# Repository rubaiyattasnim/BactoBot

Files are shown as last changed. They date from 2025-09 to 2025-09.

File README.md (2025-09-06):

# BactoBot: A Low-Cost, Bacteria-Inspired Soft Underwater Robot

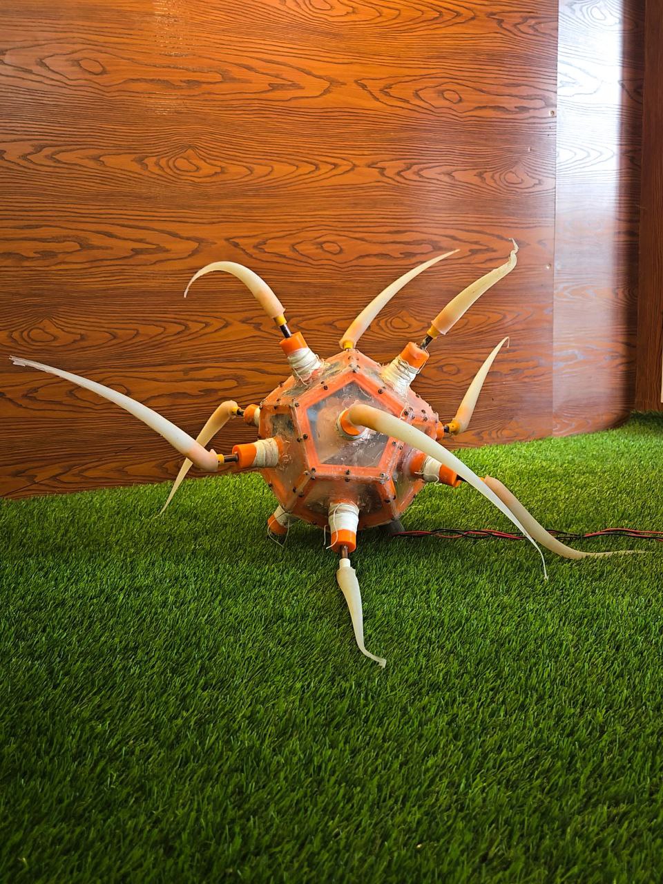
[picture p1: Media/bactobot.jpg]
BactoBot

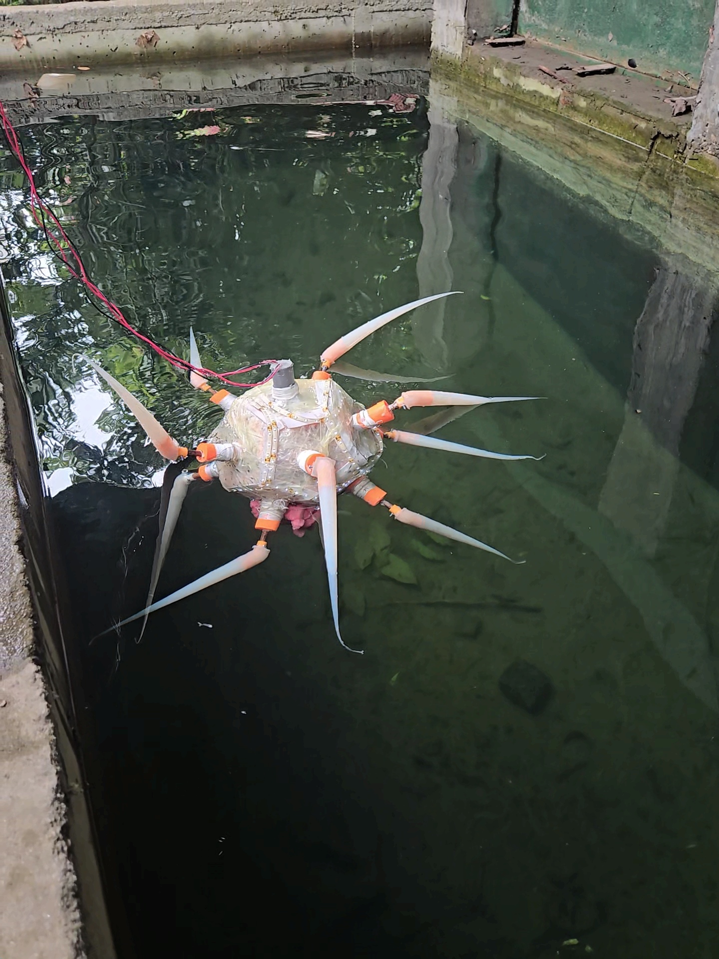
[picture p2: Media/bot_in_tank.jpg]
BactoBot operating in the test tank


BactoBot is a low-cost, soft underwater robot designed for safe and gentle marine exploration. It is inspired by the highly efficient flagellar propulsion of bacteria and built with accessible, DIY-friendly methods. This project was developed for the ME366: Electro-Mechanical System Design and Practice course at Bangladesh University of Engineering & Technology (BUET).

**[Watch the BactoBot in Action on YouTube](https://youtube.com/playlist?list=PLP1MpXDFlhkGGiaM0PEvsT2b7slWMGMUH&si=1uSfNwjm8kVEyjde)**

---

## Concept and Inspiration

Traditional rigid ROVs, with their high-speed propellers, pose a significant risk to delicate ecosystems like coral reefs. This project draws its primary inspiration from the **ZodiAq** robot, a groundbreaking design from Khalifa University, which demonstrated the potential of using multiple flexible, bacteria-like flagella for underwater locomotion.

BactoBot serves as an accessible, open-source implementation of this concept. By leveraging 3D printing, silicone molding, and common hobbyist electronics, it aims to provide a functional proof-of-concept for a safer, more compliant class of underwater drones.

*   **Primary Reference:** Mathew, A. T., et al. (2025). "ZodiAq: An Isotropic Flagella-Inspired Soft Underwater Drone for Safe Marine Exploration." *Soft Robotics*.
*   **DOI:** [10.1089/soro.2024.0036](https://doi.org/10.1089/soro.2024.0036)
*   **Preprint:** [arXiv:2403.19556](https://arxiv.org/abs/2403.19556)

## Table of Contents
- [Key Features](#key-features)
- [System Architecture](#system-architecture)
  - [Mechanical Design](#mechanical-design)
  - [Electrical System](#electrical-system)
- [Bill of Materials (BOM)](#bill-of-materials-bom)
- [Build Instructions](#build-instructions)
- [Future Work & Research Directions](#future-work--research-directions)
- [Contributors](#contributors)
- [Supervisors & Acknowledgements](#supervisors--acknowledgements)
- [License](#license)

## Key Features
- **Soft, Flexible Actuators:** 12 silicone-molded flagella that passively deform into a propulsive helical shape when rotated.
- **Redundant & Robust Design:** A 12-faced dodecahedron frame provides inherent redundancy; the robot can maintain mobility even with the failure of one or more arms.
- **Low-Cost & Replicable:** Built with readily available components and 3D-printed parts, making the design accessible to other researchers and hobbyists.
- **Inherently Safe:** The propeller-less design and soft arms minimize the risk of damaging fragile marine life during exploration.

## System Architecture

### Mechanical Design
The core structure is a **dodecahedron frame** assembled from 12 3D-printed PETG faces, providing symmetric mounting points for the actuators. The 12 propulsive **flagella** were molded from food-grade silicone rubber for high flexibility and safety. Each flagellum is coupled to a motor shaft via a rigid, 3D-printed hook embedded during casting.

- **CAD Files:** All design files, in both native SolidWorks (`.SLDPRT`) and universal STEP (`.step`) formats, are available in the `/CAD` directory.

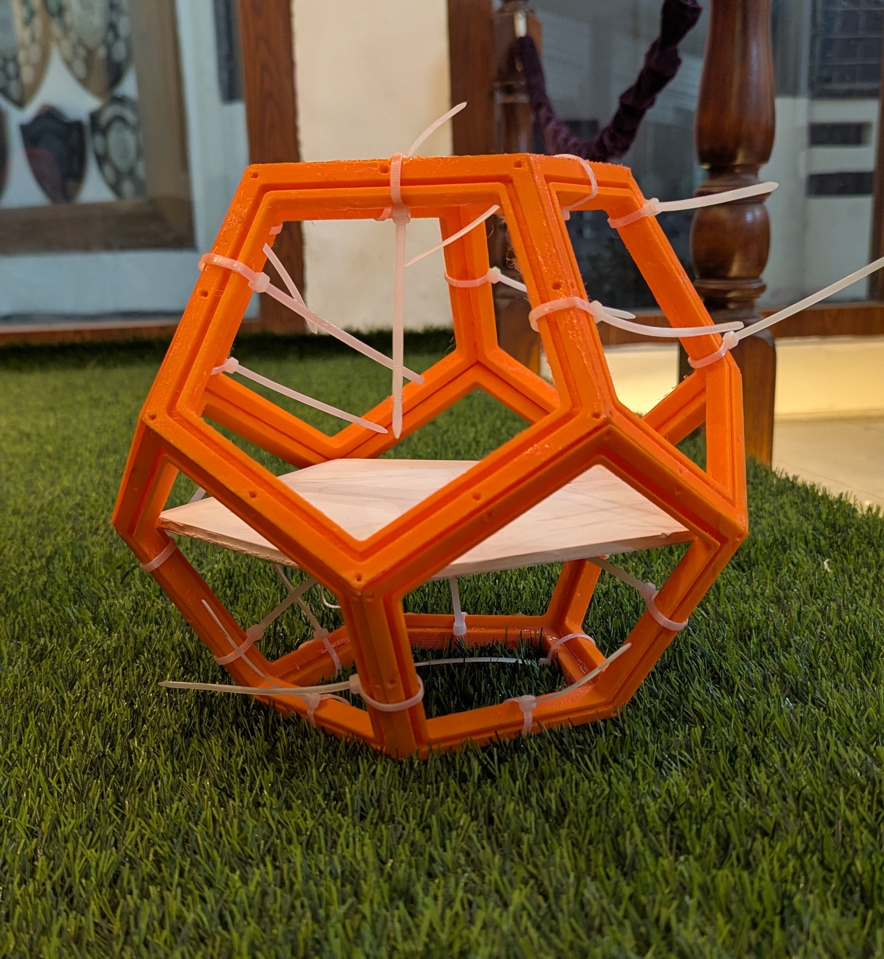
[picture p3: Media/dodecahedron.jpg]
The 3D-printed PETG dodecahedron frame during assembly.

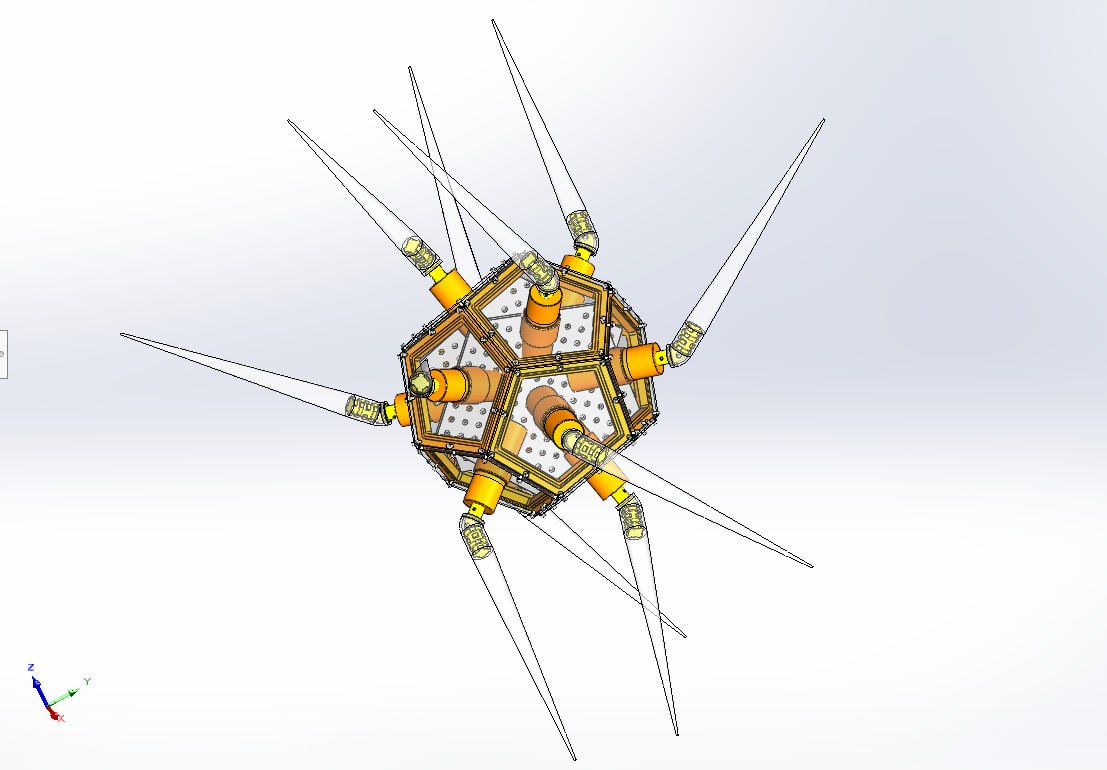
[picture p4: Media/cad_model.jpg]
Final CAD assembly showing the arrangement of the 12 flagella.


### Electrical System
The system is controlled by an **Arduino Mega 2560**. To accommodate significant space constraints within the dodecahedron frame, the 12 motors are driven in opposing pairs. Each pair is wired in parallel and controlled by a single **BTS7960 High-Current H-Bridge**, for a total of 6 driver modules.

This parallel configuration is highly effective for the primary maneuvers of forward motion, reverse, and turning. The primary trade-off for this space-saving design is the loss of individual control over each of the 12 flagella.

A buck converter steps down the main battery voltage to provide stable 5V power to the Arduino via its `VIN` pin.

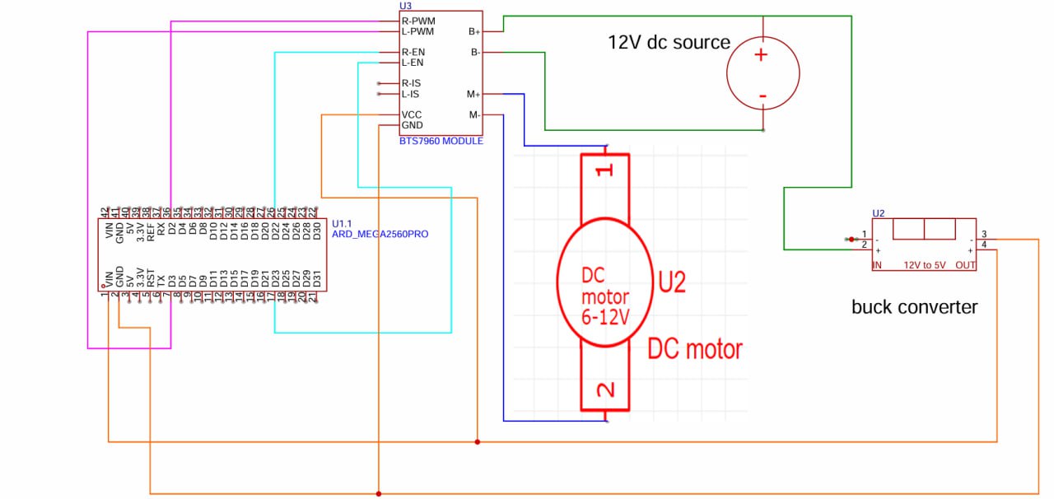
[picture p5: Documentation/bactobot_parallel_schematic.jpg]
Schematic showing two motors wired in parallel to a single driver unit. This circuit is replicated 6 times.


## Bill of Materials (BOM)
The total estimated cost at the time of construction was approximately **43,359 BDT (~$370 USD)**.

<details>
<summary><b>Click to expand the full Bill of Materials</b></summary>

### Electrical Components
| Component | Quantity | Notes |
| --- | --- | --- |
| Arduino Mega 2560 R3 | 1 | Central microcontroller. |
| BTS7960 Motor Driver Module| 6 | High-current H-bridge. See Electrical System section for wiring. |
| DC Geared Motor | 12 | 12V, 100RPM, 25GA High Torque. |
| 3S LiPo Battery | 1 | 3300mAh with XT60 connector recommended. |
| Jumper Wires & Hookup Wire | 1 Set | Assorted lengths and gauges for signal and power. |

### Structural & Mechanical Components
| Component | Quantity | Notes |
| --- | --- | --- |
| Silicone Rubber | ~1.75 kg | For molding the 12 flexible flagella. |
| 3D Printed Parts | 1 Set | PETG filament. Includes frame, motor canisters, hooks, and molds. |
| Laser Cut Faceplates | 12 | Acrylic or similar waterproof material. |
| Motor Shafts | 12 | Mild Steel. |
| Fasteners | 1 Set | Assorted M3 screws, cord screws, nuts, and bolts. |
| Adhesives | 1 Set | Epoxy and B7000 for permanent assembly. |

### Waterproofing & Buoyancy Components
| Component | Quantity | Notes |
| --- | --- | --- |
| O-Rings | ~31 | 16 Small, 15 Large for sealing motor shafts and faceplates. |
| Sealants & Lubricants | 1 Set | Silicone sealant, grease, and light machine oil. |
| Tapes & Consumables | 1 Set | Thread seal tape, electrical tape, foam, etc. |
| Ballast Weights | ~5 kg | Lead or steel weights for achieving neutral buoyancy. |

</details>

## Build Instructions
This guide outlines the fabrication and assembly of the BactoBot prototype.

### 1. Component Fabrication
-   **3D Printing:** Using the files in `/CAD`, print all structural components (frames, motor cannister assmeblies, flagellar hooks). **PETG** is recommended.
-   **Silicone Molding:** Cast **12 flexible flagella** using the 3D-printed molds. Remember to embed a rigid `Hook` at the base of each arm before the silicone cures.
-   **Laser Cutting:** Cut **12 hexagonal faceplates** from 3mm acrylic sheet. Include 2 racks to hold the electronics inside the structure.

### 2. Mechanical & Electrical Assembly
-   **Frame Construction:** Assemble the 12 printed faces into a **dodecahedron** using strong epoxy.
-   **Motor Installation:** Mount the 12 DC motors inside their dedicated canisters.
-   **Wiring:** Install the Arduino, motor drivers, and all wiring according to the provided **schematic**. Ensure all connections are secure before sealing.

### 3. Waterproofing
This step is critical and requires meticulous attention to detail.
-   Follow the **multi-layer sealing protocol** detailed in the `/Documentation` folder.
-   Key steps include creating the dynamic **O-ring and grease seals** for the 12 rotating shafts and sealing all faceplates with silicone.
-   **Perform incremental leak tests** in shallow water before fully submerging the robot.

### 4. Software and Calibration
-   **Firmware Upload:** Upload the Arduino sketch from `/Code` to the microcontroller.
-   **Buoyancy Calibration:** In a test tank, add internal ballast weights incrementally until the robot achieves stable **neutral buoyancy**.

## Future Work & Research Directions
The current prototype successfully validates the core mechanical design and propulsion concept using a simple, open-loop control script. This provides a solid foundation for significant advancements, primarily in software, control systems, and autonomy. The following is a proposed roadmap for transforming BactoBot from a proof-of-concept into a capable research platform.

### 1. Advanced Software Architecture & Control
-   **Develop a Modular Control Library:** Refactor the current hardcoded Arduino script into a clean, function-based library. Create functions like `moveForward(speed)`, `turn(direction, speed)`, and `setFlagellaState(motor_index, state)`, which will make the code more readable, scalable, and easier to build upon.
-   **Implement a State Machine:** Transition from a simple time-based loop to a robust state machine (e.g., `IDLE`, `MOVING_FORWARD`, `TURNING`, `STATION_KEEPING`). This is essential for managing complex tasks and behaviors.

### 2. Real-Time Teleoperation
-   **Integrate Wireless Communication:** Add a wireless communication module (like Bluetooth or Wi-Fi) to enable real-time remote control.
-   **Develop a Ground Control Station:** Create a simple computer- or phone-based interface to send commands to the robot, view status data, and manually control its movement.

### 3. Closed-Loop Control & Stabilization
-   **Integrate an Inertial Measurement Unit (IMU):** This is the most critical hardware upgrade. An IMU (like the MPU-6050) provides real-time orientation feedback (roll, pitch, yaw).
-   **Develop a PID Control System:** Use the IMU data to implement a PID (Proportional-Integral-Derivative) controller to maintain a heading, perform precise turns, and achieve station-keeping.

### 4. Environmental Perception & Autonomy
-   **Add a Sensor Suite:** Enhance the robot with exteroceptive sensors like waterproof cameras for visual feedback, sonar for obstacle detection, and a depth sensor to maintain specific depths.
-   **Develop Autonomous Navigation Algorithms:** With a full sensor suite, research can then focus on implementing foundational robotics algorithms like obstacle avoidance and waypoint navigation.

## Contributors
*   **Ronojoy Roy** (Student ID - 2110142)
*   **Nayan Bala**  (Student ID - 2110158)
*   **Rubaiyat Tasnim Chowdhury**  (Student ID - 2110163)
*   **Tarek Mahmud**  (Student ID - 2110177)

## Supervisors & Acknowledgements
We express our sincere gratitude to our project supervisors for their invaluable guidance:
*   Dr. Kazi Arafat Rahman, Associate Professor, ME, BUET
*   Priom Das, Assistant Professor, ME, BUET
*   Sadia Tasnim, Lecturer, ME, BUET
*   Md. Moyeenul Hossain Ratul, Lecturer, ME, BUET

## License
This project is licensed under the MIT License. See the [LICENSE](LICENSE) file for details.

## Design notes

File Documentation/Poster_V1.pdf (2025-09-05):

# BactoBot - A Bacteria Inspired

# Underwater Soft Robot

## Abstract

## KEY COMPONENTS & MATERIALS

## FUTURE PROSPECTS

## PROJECT SUPERVISORS

## PREPARED BY

## For the course of ME 366: Electro-Mechanical System Design & Practice

## CHALLENGES & LIMITATIONS

## OPERATIONAL FLOW

## HOW IT WORKS: A FLAGELLAR PROPULSION SYSTEM

## KEY FEATURES

BactoBot is a soft underwater robot designed for safe marine exploration. Inspired by the whip-like tails (flagella) of bacteria, BactoBot has 12 flexible arms arranged in a dodecahedron shape. This

design makes it gentle for interacting with marine life and allows it to keep working even if some arms break. Utilizing readily available components, 3D printing, and accessible microcontrollers, we developed a bot capable of basic underwater navigation in controlled environments like tanks or pools.

Microcontroller: Arduino

Mega 2560 | Motor Driver: BTS 7960 43A | Motors: 12x High Torque DC
| | Geared Motors

Battery: 3300mAh 11.1V 3S
Lipo Battery

Power Management: On/Off
Slide Switch

Body Structure: 3D Printed Frame (PETG)

Front Faceplate: Acrylic

Sheet

Flexible Flagella: Molded Soft Silicone Rubber (Food Grade)

Others: Breadboard, Wiring, Waterproofing Sealants,

ballast

Showcasing the full potential of omnidirectional movement capabilities Implementing closed-loop control with an IMU for precise navigation Integrating sensors like cameras for enhanced perception
Improving battery life and power efficiency
Enhancing structural integrity and waterproofing for deeper operation Developing autonomous navigation capabilities.

Dr. Kazi Arafat Rahman, Associate Professor, ME, BUET Priom Das, Assistant Professor, ME, BUET
Md. Moyeenul Hossain Ratul, Lecturer, ME, BUET Sadia Tasnim, Lecturer, ME, BUET

Waterproofing: Achieving a reliable and watertight seal for all 12 rotating shafts and the main structural body was extremely challenging, especially while working within a limited budget. This was our primary and most persistent engineering challenge throughout development.

Control System: Our current control system is open-loop, meaning we can issue commands to the

motors, but the robot receives no feedback on its actual position or orientation. This lack of sensory input causes the system to gradually drift, reducing overall precision.

Buoyancy & Ballast: Precisely adjusting the robot to achieve neutral buoyancy is a slow and iterative process, involving repeated trial and error with different ballast weight configurations. Even

small changes in hardware or conditions can require re-balancing.

| Bacteria-Inspired Propulsion: Utilizes rotating flexible flagella, mimicking bacterial movement for efficient underwater thrust

| Soft Robotics Approach: Incorporates soft, compliant flagella for potentially safer interaction with the environment

| Redundancy: If one arm fails, others compensate, making the robot reliable in rough underwater environments

| Omnidirectional Movement: Designed for translation in multiple directions and rotation around its axis

| Low-Cost & DIY: Built using accessible components and 3D printing, making it cost-effective.

Simple Rotation, Complex Motion: A motor that generates a simple rotating force is located at the base of each soft arm. At first, the arm itself has a straight form rather than a propeller-like one.

Passive Deformation of Soft Arm: The flexible arm passively bends and twists into a stable helical shape as the motor spins it in the water. This is due to the hydrodynamic force of the water and the torque of the motor.

Thrust Generation: | The drone is propelled by | the thrust produced by this rotating
helix-shaped arm | pushing against the water.
CONCEPTUAL DESIGN | CAD MODELING | 3D PRINTING PARTS
ELECTRONIC ASSEMBLY | FRAME ASSEMBLY | WATERPROOFING & TESTING
PROGRAMMING & CALIBRATION | UNDERWATER TRIALS

Ronojoy Roy
2110142

Nayan Bala
2110158

Rubaiyat Tasnim
Chowdhury
2110163

Tarek Mahmud
2110177

# Bangladesh University of Engineering & Technology

Prepared by the students of

Scan QR Code to
Learn more

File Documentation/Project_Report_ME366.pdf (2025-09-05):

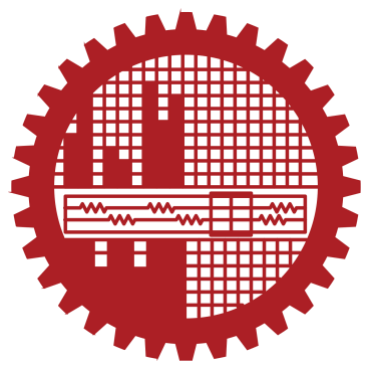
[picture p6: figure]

### Bangladesh University of Engineering & Technology (BUET)

Department of Mechanical Engineering

ME366: Electro-Mechanical System Design and Practice

Project Report: BactoBot

A Low-Cost, Bacteria-Inspired Soft Underwater Robot for Marine Exploration

Prepared By: Group C-11

- Ronojoy Roy (2110142)
- Nayan Bala (2110158)
- Rubaiyat Tasnim Chowdhury (2110163)
- Tarek Mahmud (2110177)

Project Supervisors:

- Dr. Kazi Arafat Rahman, Associate Professor, ME, BUET
- Priom Das, Assistant Professor, ME, BUET
- Sadia Tasnim, Lecturer, ME, BUET
- Md. Moyeenul Hossain Ratul, Lecturer, ME, BUET

Date: 31/07/2025

Abstract

Traditional rigid underwater vehicles pose risks to delicate marine ecosystems, such as coral reefs, due to their inflexible structures and high-speed propellers. This project, "BactoBot," addresses this challenge by developing a soft underwater robot designed for safe and gentle marine exploration. Inspired by the highly efficient flagellar propulsion of bacteria, BactoBot features 12 flexible, silicone-based arms arranged on a dodecahedral frame. This design provides inherent compliance, redundancy against single-point failures, and the potential for omnidirectional movement. Utilizing readily available components, 3D printing, and accessible microcontrollers, we successfully designed, fabricated, and tested a low-cost prototype capable of basic underwater navigation, including forward motion and turning, in a controlled environment. The project demonstrates the feasibility of replicating complex biological locomotion principles using DIY methods, paving the way for more affordable and environmentally-conscious robotic tools for marine science.

Table of Contents

### 1. Introduction

### 1.1 The Challenge of Underwater Exploration

The world's oceans are vast ecosystems teeming with life, much of which remains unexplored. Exploring delicate environments like coral reefs, underwater caves, and cluttered seabeds presents a significant challenge for robotics. Conventional Remotely Operated Vehicles (ROVs) are often rigid and powered by fast-spinning propellers, which can inadvertently damage fragile marine life and their habitats. The need for a safer, more adaptable, and accessible robotic platform is paramount for non-invasive marine research. The paradigm of soft robotics offers a compelling solution, enabling robots to interact with their environment in a safer, simpler, and more cost-effective manner.

### 1.2 Project Inspiration: Bacterial Flagella

This project draws its primary inspiration from one of nature's most efficient and unlikely swimmers: bacteria. The bacterial flagellum is the only known example of a true biological "wheel," a simple rotational motor that propels the organism. This project aims to replicate this unique locomotion strategy at a macro scale.

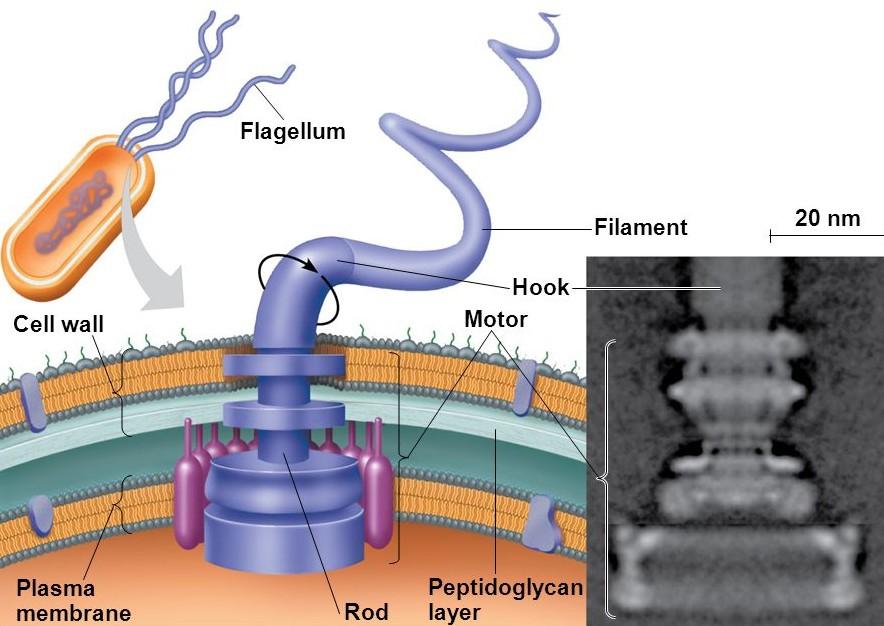
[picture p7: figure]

Figure 1: Structure of a Prokaryotic Flagellum, with motor, rigid hook and flexible filament.

### 1.3 Project Objectives

The primary goal of the BactoBot project was to design and build a budget-friendly, soft underwater robot based on the flagellar propulsion concept. Key objectives included:

- To design a redundant and robust mechanical structure using accessible materials.
- To replicate the passive deformation principle of flagellar propulsion.
- To implement a control system for basic underwater maneuvers (forward motion and turning).
- To overcome the practical engineering challenges of waterproofing and buoyancy on a limited budget.

### 2. Design and Fabrication

### 2.1 Mechanical Design

The mechanical structure of BactoBot was designed for robustness, redundancy, and ease of fabrication.

Body Frame: The core structure is a dodecahedron (a 12-faced shape) fabricated from 3D-printed PETG. This geometry was chosen because it allows for the symmetric placement of 12 arms, providing inherent design redundancy and the potential for omnidirectional movement.

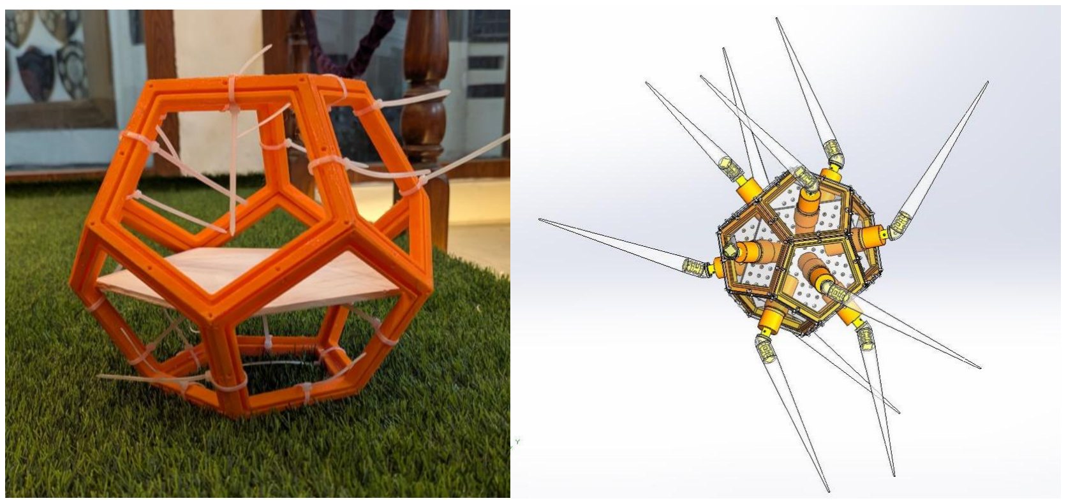
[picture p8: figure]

Figure 2: (Left) The 3D-printed dodecahedron frame. (Right) CAD model showing the full assembly.

Flagella: The 12 propulsive arms were molded from food-grade silicone rubber. This material makes the flagella highly flexible and safe for potential environmental interaction.

Each flagellum is designed as a straight, tapered arm that deforms passively into a propulsive shape in water.

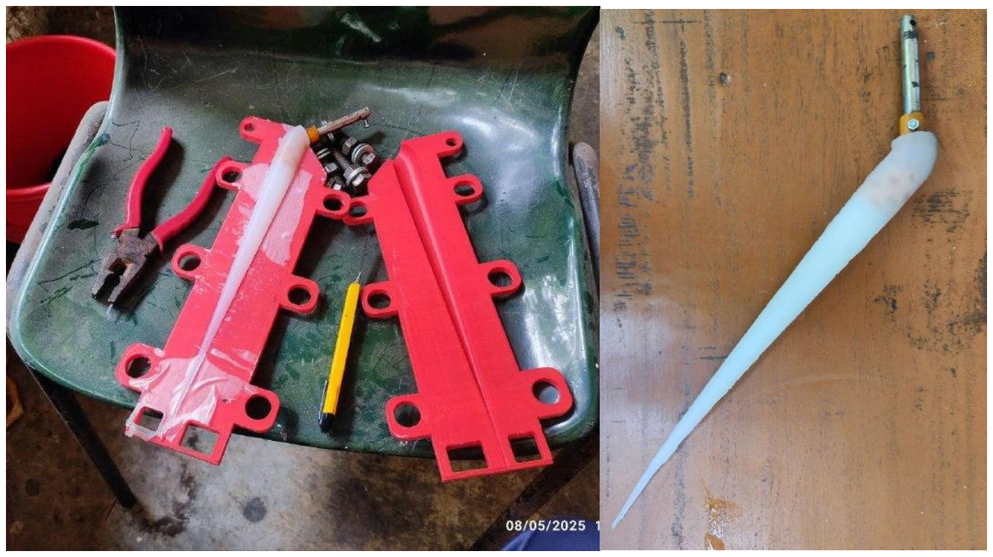
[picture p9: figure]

Figure 3: (Left) Flagellum inside its mold. (Right) Flagellum with hook and motor shaft attached.

Waterproofing: Sealing the main body and 12 rotating motor shafts was a primary challenge. A multi-layered approach was used:

- Acrylic faceplates for each of the 12 faces.
- Specially designed, 3D-printed canisters to house the motors.
- O-rings to create a primary seal.
- Waterproof sealants (silicone, thread tape, grease) applied to all joints and potential points of ingress.

### 2.2 Electrical System and Actuation

The electrical system was designed with widely available and robust components suitable for a DIY project.

- The Brain: An Arduino Mega 2560 serves as the central microcontroller, chosen for its large number of I/O pins and strong community support.
- Actuation: Propulsion is driven by 12 high-torque DC geared motors, one for each flagellum.

- Motor Control: Each motor is controlled by a dedicated BTS7960 high-current motor driver, allowing for precise control of speed and direction.
- Power: The entire system is powered by a high-discharge 11.1V (3S) LiPo battery.

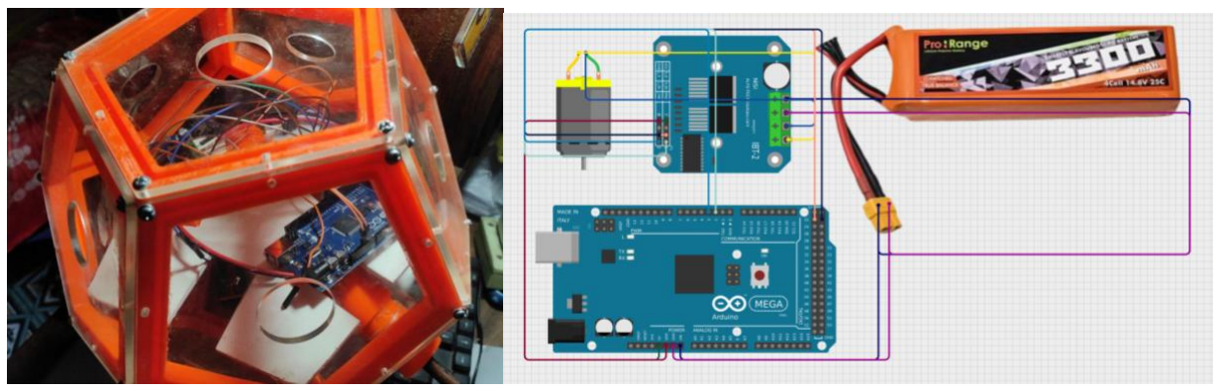
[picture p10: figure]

Figure 4: (Left) The assembled electronics inside the frame. (Right) The basic circuit diagram for a single motor.

### 3. Flagellar Locomotion Principle

### 3.1 Passive Deformation for Propulsion

Unlike a conventional propeller, BactoBot's locomotion is not based on a pre-formed rigid blade. Instead, it relies on the principle of passive deformation, a core concept in soft robotics.

1. A simple rotational torque is applied at the base of each straight, flexible arm by the DC motor.
2. As the arm rotates in the water, hydrodynamic forces cause it to bend and twist.
3. The arm passively deforms into a stable, helical (corkscrew) shape.
4. This rotating helical shape acts as a propeller, generating thrust by pushing against the water.

This method allows for complex propulsive motion to be generated from a very simple input (rotation), with the physics of the soft material and fluid interaction handling the complexity.

### 3.2 Control Strategy for Movement

By coordinating the rotation of the 12 arms, different maneuvers can be achieved. Our current implementation is open-loop.

- Forward Motion: To move in a straight line, opposing pairs of motors are activated. By rotating in directions that cancel out their rotational torques on the main body, a net thrust is generated, pushing the robot forward.

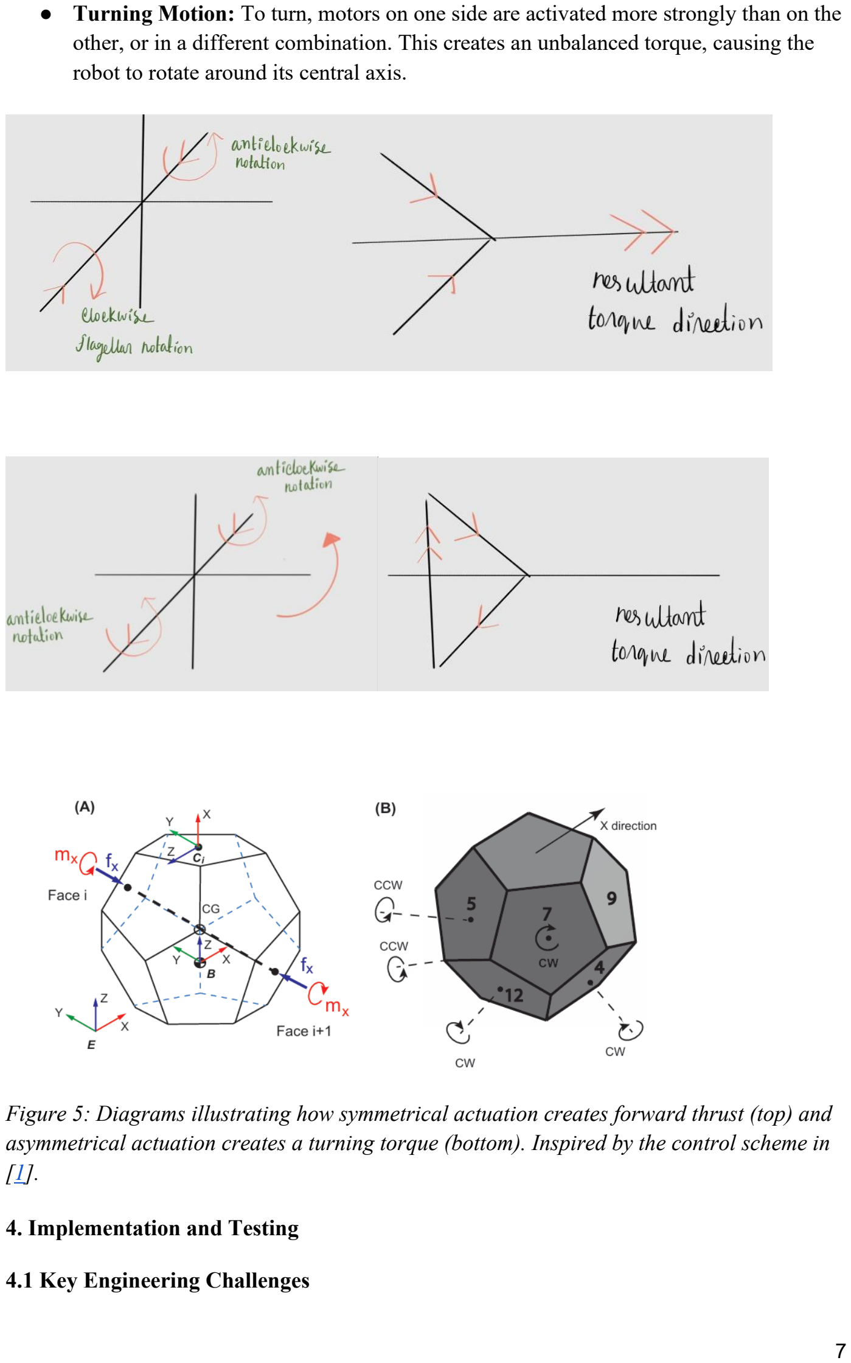
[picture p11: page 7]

- Turning Motion: To turn, motors on one side are activated more strongly than on the other, or in a different combination. This creates an unbalanced torque, causing the robot to rotate around its central axis.

Figure 5: Diagrams illustrating how symmetrical actuation creates forward thrust (top) and asymmetrical actuation creates a turning torque (bottom). Inspired by the control scheme in [1].

### 4. Implementation and Testing

### 4.1 Key Engineering Challenges

- Waterproofing: Achieving a reliable, dynamic seal for 12 rotating shafts on a budget was our primary engineering challenge. Our strategy involved multiple layers of protection, from O-rings to liberal use of silicone sealant and poly-wrapping the entire robot during initial tests. This iterative process of sealing, testing, and re-sealing was critical to the project's success.
- Buoyancy and Ballast: Precisely balancing the robot to be neutrally buoyant was a tedious process of trial and error. Small ballast weights had to be carefully added and positioned inside the frame to counteract the weight of the components and achieve a stable orientation in the water.

### 4.2 Testing Environment and Results

BactoBot was successfully tested in a controlled tank environment. The tests validated the core design and functionality of the prototype.
The key results were:
1. No Water Leaks: The multi-layered waterproofing strategy proved effective during the testing period.
2. Achieved Locomotion: The robot successfully demonstrated both forward motion and turning maneuvers based on the open-loop commands sent to the motors.
3. Stable Operation: The robot maintained a stable orientation and depth during basic maneuvers, confirming the success of the buoyancy and ballast balancing.

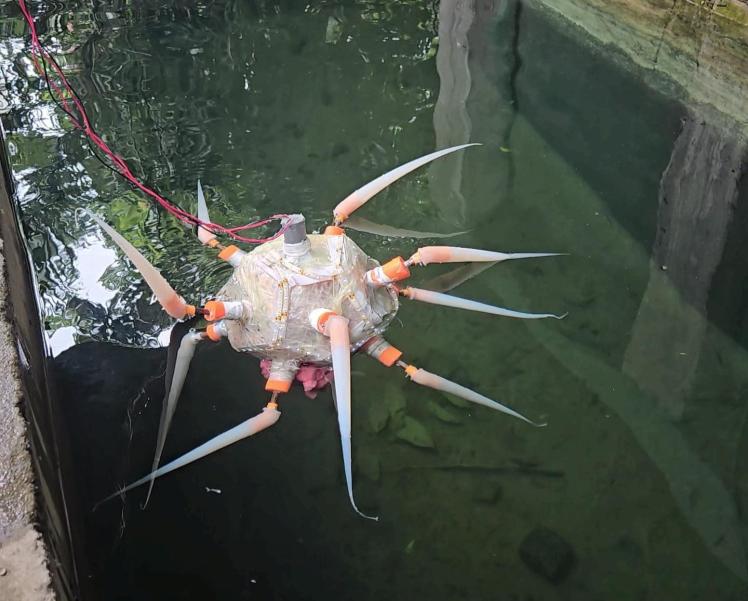
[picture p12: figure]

Figure 6: BactoBot submerged and operating in the test tank.

Watch here:
https://youtube.com/playlist?list=PLP1MpXDFlhkGGiaM0PEvsT2b7slWMGMUH&si=1uSfNwjm8k VEyjde (https://youtube.com/playlist?list=PLP1MpXDFlhkGGiaM0PEvsT2b7slWMGMUH&si=1uSfNwjm8kVEyjde)

### 5. Conclusion and Future Work

### 5.1 Conclusion

This project successfully met its objectives to design, build, and test a low-cost, bacteria-inspired soft underwater robot. We proved that the advanced concept of flagellar propulsion can be replicated using accessible DIY methods and materials. BactoBot stands as a functional proof-of-concept, demonstrating a promising path towards creating safer, more affordable, and more accessible robots for the critical task of marine exploration.

### 5.2 Recommendations for Future Work

BactoBot provides a solid foundation for further development. Future work should focus on:

- Implementing Closed-Loop Control: Integrating an Inertial Measurement Unit (IMU) to provide feedback on the robot's orientation. This would allow for a closed-loop control system for precise navigation and station-keeping.
- Enhanced Perception: Integrating sensors like waterproof cameras to provide a visual feed, transforming the robot from a purely locomotive platform to a true exploration tool.
- Improved Waterproofing and Durability: Refining the mechanical design for more robust and long-term waterproofing to allow for deeper and more extended operation.
- Autonomous Navigation: Developing algorithms for autonomous navigation to allow the robot to perform exploration tasks with minimal human intervention.

### 6. Acknowledgements

We would like to express our sincere gratitude to our project supervisors—Dr. Kazi Arafat Rahman, Priom Das, Sadia Tasnim, and Md. Moyeenul Hossain Ratul—for their invaluable guidance, support, and encouragement throughout this project.

### 7. References

[1] Mathew, A. T., Feliu-Talegon, D., Abdullahi Adamu, Y., et al. (2025). "ZodiAq: An Isotropic Flagella-Inspired Soft Underwater Drone for Safe Marine Exploration." Soft Robotics. Published at: https://doi.org/10.1089/soro.2024.0036. (Preprint available at: https://arxiv.org/abs/2403.19556)

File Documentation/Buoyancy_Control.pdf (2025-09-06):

# Achieving Neutral Buoyancy in Underwater Robotics

In our aquatic robotics project, we meticulously controlled buoyancy using the neutral buoyancy method. This involves precisely adjusting the robot's mass until its overall density matches that of water. Our process involved a combination of theoretical calculations and practical experimentation.
We leveraged SolidWorks for accurate volume determination and cross-referenced this with ChatGPT for predictive mass estimations required to achieve neutral buoyancy. This dual approach provided a strong foundation for our weight distribution strategy.
The iterative trial-and-error process was crucial. We incrementally added weights, starting with six 500g weights and then two 1kg weights, refining the robot's submergence. The final adjusted total weight for neutral buoyancy was approximately 11.25 kg.

Volume Calculation
Initial volume determined via SolidWorks
and validated through AI-assisted
computations for mass prediction.

Iterative Weighting
Deployment of 500g and 1kg weights in a trial-and-error approach to fine-tune buoyancy.

Target Buoyancy Achieved
Successful neutral buoyancy attained at a cumulative mass of 11.25 kg, ensuring stable underwater operation.

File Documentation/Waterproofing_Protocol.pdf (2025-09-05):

# Advanced Waterproofing Techniques for Electrical and Mechanical Assemblies

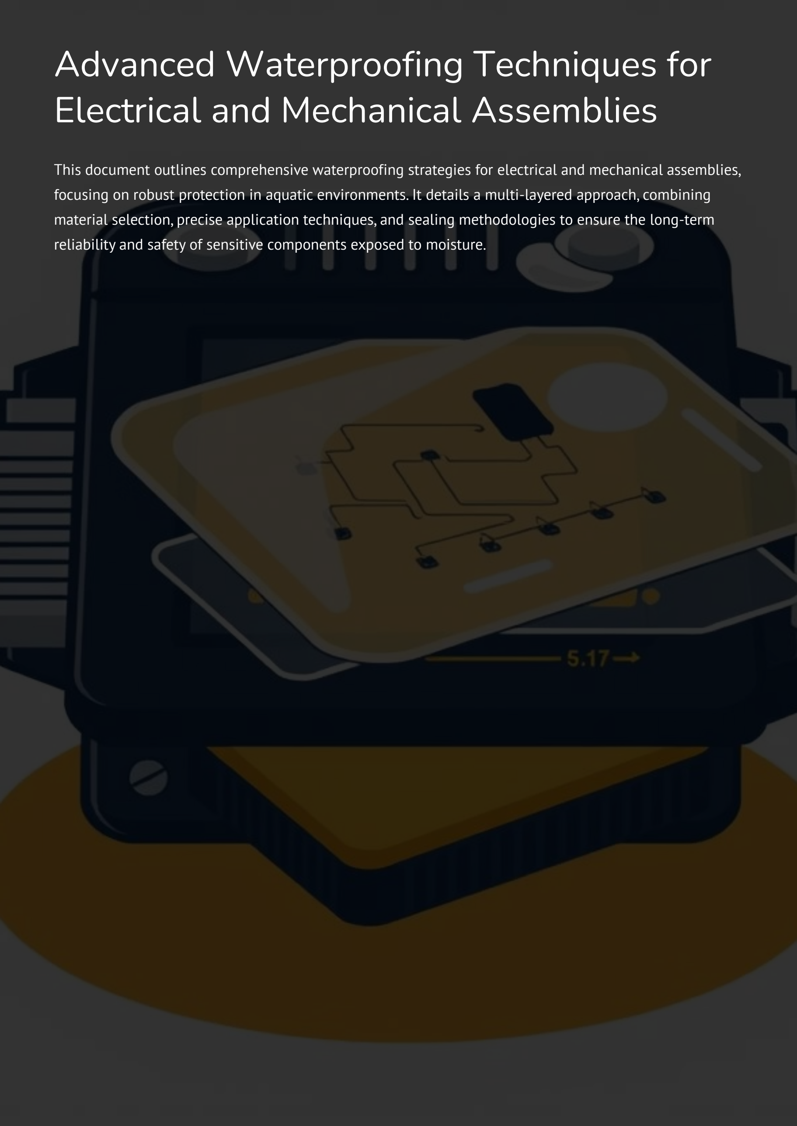
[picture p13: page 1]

This document outlines comprehensive waterproofing strategies for electrical and mechanical assemblies, focusing on robust protection in aquatic environments. It details a multi-layered approach, combining material selection, precise application techniques, and sealing methodologies to ensure the long-term reliability and safety of sensitive components exposed to moisture.

# Multi-Layered Waterproofing Protocol for Aquatic Systems

Effective waterproofing in aquatic projects demands a meticulous, multi-tiered approach to safeguard sensitive electrical and mechanical components from water ingress and potential damage. Our protocol integrates primary, secondary, and tertiary barriers, ensuring redundancy and enhanced protection.

## Primary Encapsulation (Poly Wrap)

Each individual electrical component is initially wrapped using a high-density poly roll. This serves as the first line of defence, providing temporary protection against incidental water exposure during assembly or in the event of a breach in outer layers. This initial wrapping also aids in shock absorption and vibration damping.

## Terminal Sealing (Araldite & Hot Glue)

Critical entry points, such as the motor's two-wire connection points, are meticulously sealed. Araldite epoxy glue is applied to form a durable, watertight bond around these connections. Once dry, an additional layer of hot glue is applied over the cured epoxy, providing extra mechanical strength, vibration resistance, and a secondary hermetic seal. This two-stage application method significantly enhances the long-term integrity of the seal.

## Structural Edge and Joint Sealing

Following the assembly of the dodecahedron structure, all external edges are sealed with a high-performance, marine-grade sealant. Particular attention is paid to the connecting area between the main structural plates and the motor canister. Due to the confined space, Araldite epoxy is precisely applied here to create an impermeable barrier. This step prevents capillary action and direct water penetration into the assembly's interior.

Recognising the potential for residual moisture or condensation within the motor canister, an internal defence mechanism is employed. Foam, pre-saturated with Mobil oil, is strategically placed around the motor. This oil-impregnated foam serves a dual purpose: it acts as a hydrophobic barrier, repelling any water droplets, and provides continuous lubrication to the motor components, preventing corrosion and ensuring smooth operation even in humid conditions. A layer of grease is then applied over this foam for additional protection.

## Internal Motor Protection & Lubrication

The crucial joint between the motor shaft and the main shaft, housed within a small canister, is filled with high-viscosity grease. A customised O-ring is fitted on the upper part of this small canister. Furthermore, a second customised O-ring is positioned just below and inside the upper face of the main motor canister. The space between these two O-rings is generously filled with grease, creating a dynamic hydrostatic seal. A final, smaller O-ring is placed just above the upper motor canister's upper face, serving as an additional splash guard and environmental seal. This multi-O-ring and grease-filled chamber system provides unparalleled protection against water ingress along the rotating shaft.

## Advanced Shaft and O-Ring Seal System

After all internal sealing and assembly, the entire structure is wrapped multiple times with poly roll for comprehensive external protection. This layer acts as a sacrificial barrier against abrasion and minor impacts. Finally, high-strength scotch tape is applied to stabilise the poly wrap, ensuring it remains securely in place and maintains its integrity under operational conditions.

## External Reinforcement (Poly Wrap & Tape)

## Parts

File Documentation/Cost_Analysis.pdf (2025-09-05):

TABLE 1: COST ANALYSIS OF STRUCTURAL COMPONENTS

Component | Unit Cost(BDT) | Quantity | Subtotal(BDT)
Silicone | 2980/kg | 1.75kg | 5215
3D Print (Mold) | 2500 | 1 | 2500
3D Print (Frame, Canister, Hook) | 940 | 12 | 11280
Laser Cutting (Faceplate) | 175 | 12 | 2100
Shaft (Mild Steel) | 35 | 12 | 420
Screw (3-mm) | 1.75 | 150 | 260
Cord Screw | 5 | 15 | 75
Nut Bolts (Big) | 25 | 6 | 150
Nut Bolts (Small) | 6 | 15 | 90
Glue (B7000) | 150 | 2 | 300
Glue (Epoxy) | 120 | 5 | 600
Hard Board (Rack) | --- | --- | 150
Total Cost | | | 23140

TABLE 2: COST ANALYSIS OF ELECTRICAL COMPONENTS

Component | Unit Cost(BDT) | Quantity | Subtotal(BDT)
Arduino Mega 2560 R3 | 1788 | 1 | 1788
Motor Driver 43A BTS7960
| 420 | 6 | 2520
High Torque DC Gear Motor
12V 100RPM 25GA | 750 | 12 | 9000
Jumper Wires | 95 | 3 | 285
Battery | 75 | 1 | 75
Lipo Battery 3300mAh 7.4V 2S | 2750 | 1 | 2750
Wire | --- | --- | 150
Total Cost | | | 16568

TABLE 3: COST ANALYSIS OF BUOYANCY CONTROL COMPONENTS

Component | Unit Cost(BDT) | Quantity | Subtotal(BDT)
Weights (1kg) | 80 | 2 | 160
Weights (500g) | 40 | 6 | 240
Total Cost | | | 400

TABLE 4: COST ANALYSIS OF WATERPROOFING COMPONENTS

Component | Unit Cost(BDT) | Quantity | Subtotal(BDT)
Polythene | 411 | 1 | 411
Sealant | 200 | 3 | 600
O-Ring (Small) | 2.5 | 16 | 40
O-Ring (Large) | 6 | 15 | 90
Glue Stick | 20 | 5 | 100
Mobil | 300/1L | 500mL | 150
Grease (400g) | 150 | 1 | 150
Thread Tape | 20 | 8 | 160
Double Sided-Tape | 40 | 2 | 80
Scotch Tape (Large) | 40 | 1 | 40
Scotch Tape (Small) | 10 | 3 | 30
Electrical Tape | 20 | 3 | 60
Foam | 20 | 6 | 120
Epoxy | 150 | 2 | 300
Total | | | 2331

TABLE 5: SUMMARY OF OVERALL COST

Category | Total Cost(BDT)
Structural | 23140
Electrical | 16568
Buoyancy Control | 400
Waterproofing | 2331
Miscellaneous (Transport, Shipping etc) | 920
Total | 43359

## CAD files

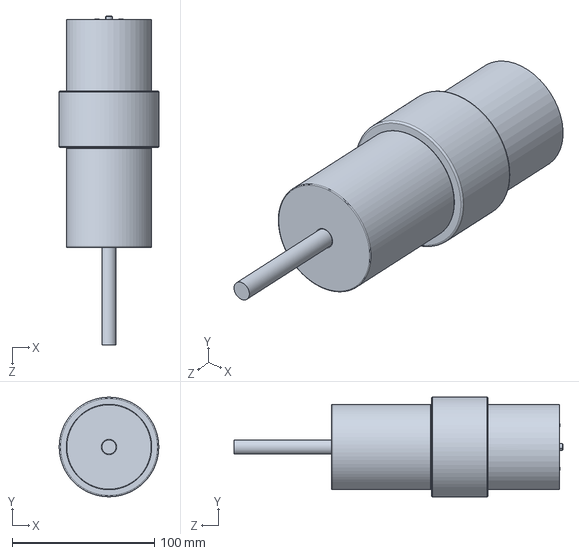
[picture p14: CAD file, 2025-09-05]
CAD/SolidWorks_Native/Motor assembly as partfile.SLDPRT
70.0 x 70.0 x 231.0 mm

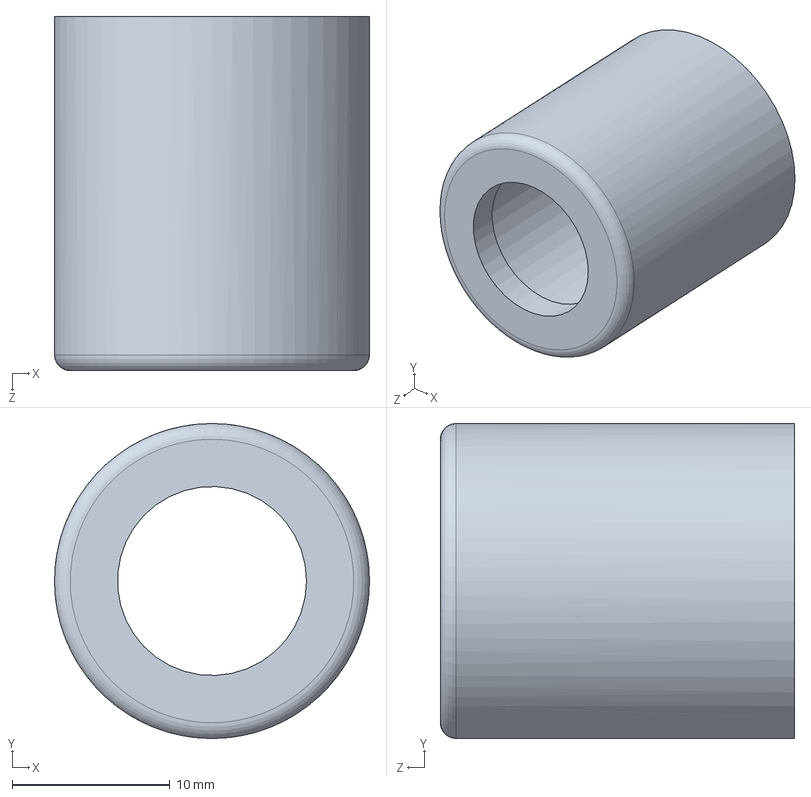
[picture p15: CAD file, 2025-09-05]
CAD/SolidWorks_Native/3D Print/Small Canister.SLDPRT
20.0 x 20.0 x 22.5 mm

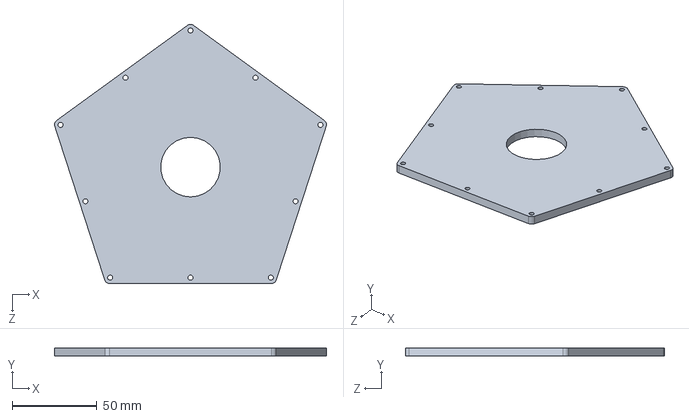
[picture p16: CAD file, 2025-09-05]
CAD/SolidWorks_Native/Plate.SLDPRT
160.7 x 5.00 x 153.2 mm

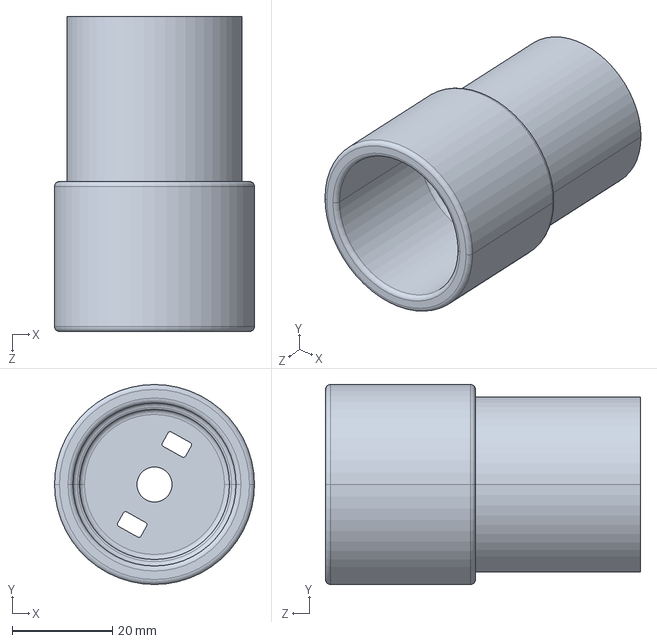
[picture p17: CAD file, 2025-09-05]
CAD/STEP_Universal/3D Print/Lower Canister.STEP
40.0 x 40.0 x 63.0 mm

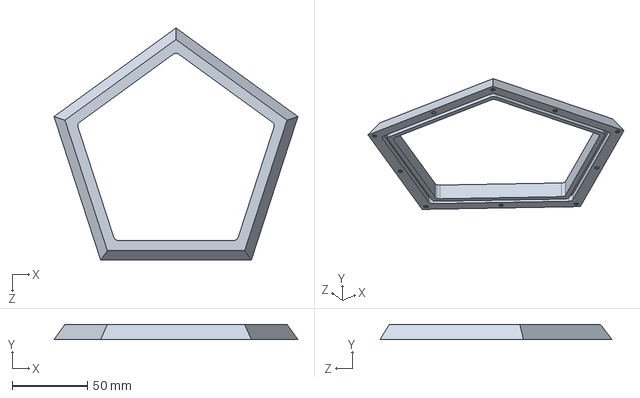
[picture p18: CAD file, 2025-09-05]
CAD/SolidWorks_Native/3D Print/Frame.SLDPRT
161.8 x 10.0 x 153.9 mm

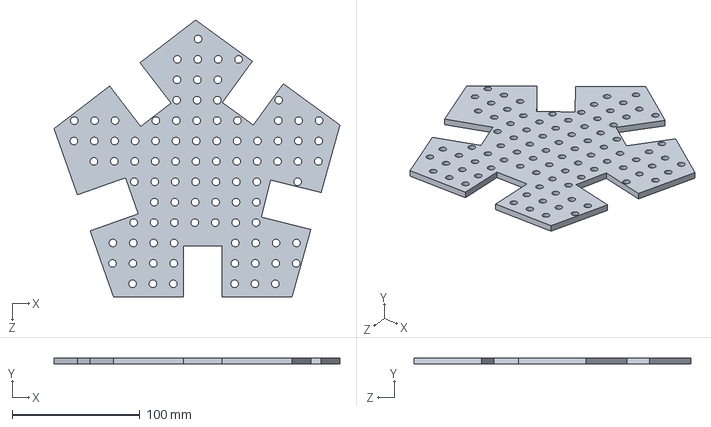
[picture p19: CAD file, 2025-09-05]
CAD/SolidWorks_Native/Rack.SLDPRT
224.3 x 5.00 x 217.2 mm

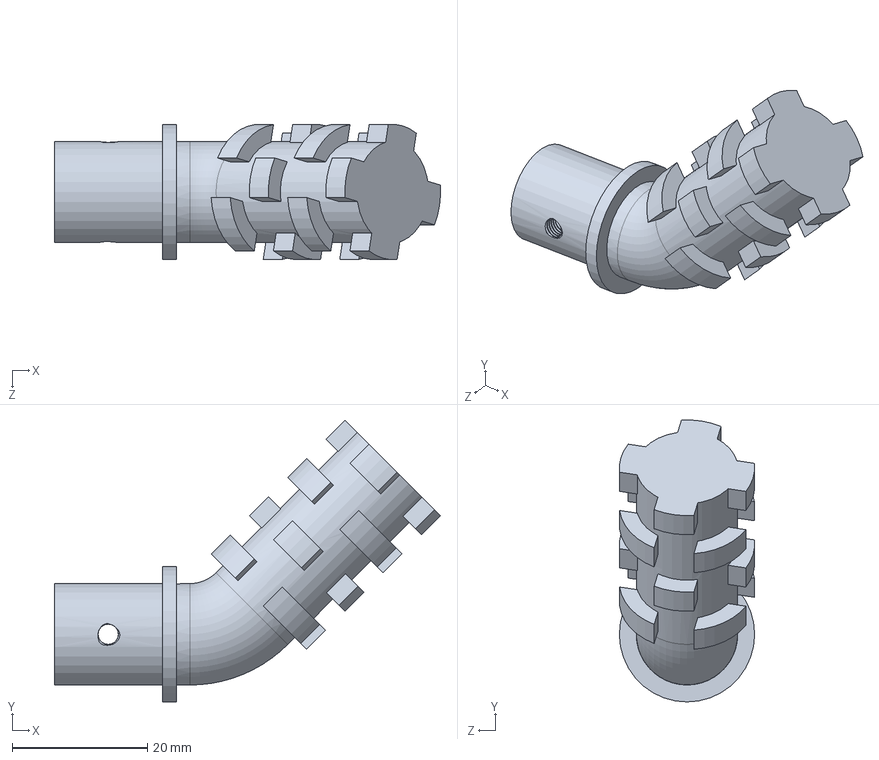
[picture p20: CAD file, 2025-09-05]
CAD/SolidWorks_Native/3D Print/Hook.SLDPRT
57.1 x 41.7 x 20.0 mm

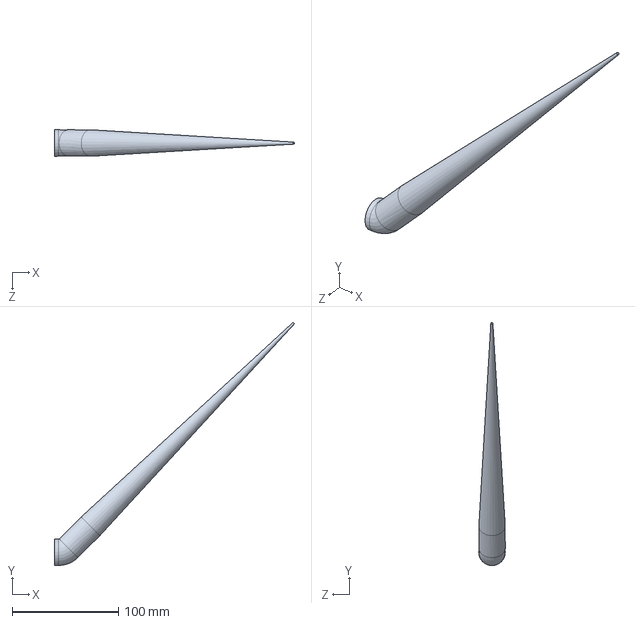
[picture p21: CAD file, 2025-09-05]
CAD/SolidWorks_Native/Flagella.SLDPRT
226.1 x 229.1 x 25.0 mm

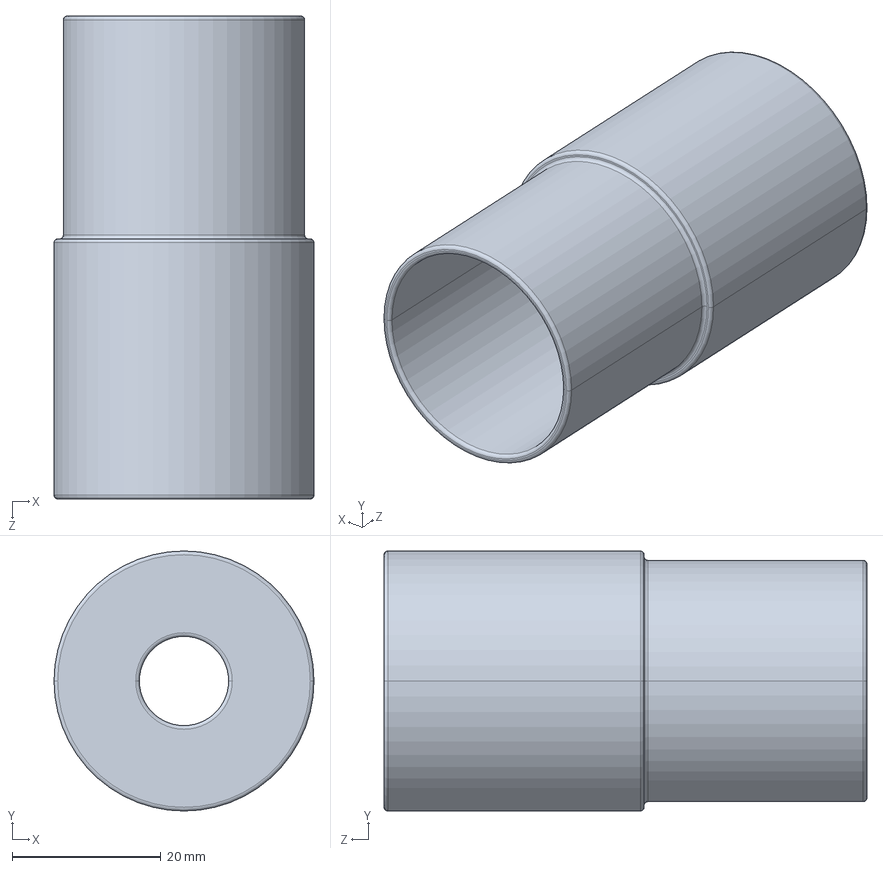
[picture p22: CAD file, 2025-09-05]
CAD/STEP_Universal/3D Print/Upper Canister.STEP
35.0 x 35.0 x 65.0 mm

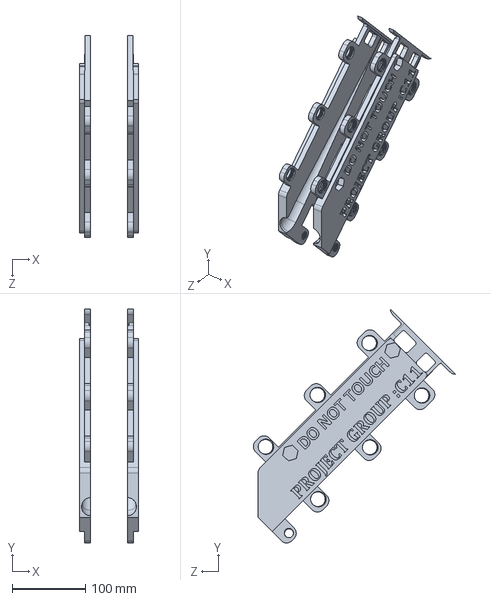
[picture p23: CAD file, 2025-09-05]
CAD/SolidWorks_Native/3D Print/Mold of Flagella -.SLDPRT
80.0 x 319.3 x 276.2 mm

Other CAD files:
CAD/STEP_Universal/Plate.STEP
CAD/STEP_Universal/3D Print/Frame.STEP
CAD/STEP_Universal/Rack.STEP
CAD/STEP_Universal/3D Print/Small Canister.STEP
CAD/SolidWorks_Native/3D Print/Lower Canister.SLDPRT
CAD/SolidWorks_Native/3D Print/Upper Canister.SLDPRT

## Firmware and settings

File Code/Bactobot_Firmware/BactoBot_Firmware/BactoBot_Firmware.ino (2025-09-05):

// Fixed sequence: M1 CW 40s, M3 CCW 40s, M2 CCW 20s then CW 20s

// Motor 1 pins
const int M1_RPWM = 2;
const int M1_LPWM = 3;
const int M1_R_EN = 22;
const int M1_L_EN = 23;

// Motor 2 pins
const int M2_RPWM = 4;
const int M2_LPWM = 5;
const int M2_R_EN = 24;
const int M2_L_EN = 25;

// Motor 3 pins
const int M3_RPWM = 6;
const int M3_LPWM = 7;
const int M3_R_EN = 26;
const int M3_L_EN = 27;

// Motor speed (0-255)
const int motorSpeed = 200;

// Simple timing variables
unsigned long startTime = 0;

void setup() {
  // Initialize all pins as outputs
  pinMode(M1_RPWM, OUTPUT);
  pinMode(M1_LPWM, OUTPUT);
  pinMode(M1_R_EN, OUTPUT);
  pinMode(M1_L_EN, OUTPUT);
  
  pinMode(M2_RPWM, OUTPUT);
  pinMode(M2_LPWM, OUTPUT);
  pinMode(M2_R_EN, OUTPUT);
  pinMode(M2_L_EN, OUTPUT);
  
  pinMode(M3_RPWM, OUTPUT);
  pinMode(M3_LPWM, OUTPUT);
  pinMode(M3_R_EN, OUTPUT);
  pinMode(M3_L_EN, OUTPUT);
  
  // Enable all motors
  digitalWrite(M1_R_EN, HIGH);
  digitalWrite(M1_L_EN, HIGH);
  digitalWrite(M2_R_EN, HIGH);
  digitalWrite(M2_L_EN, HIGH);
  digitalWrite(M3_R_EN, HIGH);
  digitalWrite(M3_L_EN, HIGH);
  
  // Initialize serial
  Serial.begin(9600);
  Serial.println("Motor Control Started - Arduino Mega");
  
  // Start timing
  startTime = millis();
}

void loop() {
  unsigned long currentTime = millis();
  unsigned long elapsedTime = currentTime - startTime;
  
  // Reset after 40 seconds
  if (elapsedTime >= 40000) {
    startTime = currentTime; // Use currentTime instead of millis() again
    Serial.println("Cycle restarted");
    return; // Exit this loop iteration to start fresh
  }
  
  // Motor 1: Always CW for full 40 seconds
  analogWrite(M1_RPWM, motorSpeed);
  analogWrite(M1_LPWM, 0);
  
  // Motor 3: Always CCW for full 40 seconds
  analogWrite(M3_RPWM, 0);
  analogWrite(M3_LPWM, motorSpeed);
  
  // Motor 2: CCW for first 20 seconds, then CW for next 20 seconds
  if (elapsedTime < 20000) {
    // First 20 seconds: Motor 2 CCW
    analogWrite(M2_RPWM, 0);
    analogWrite(M2_LPWM, motorSpeed);
    
    // Debug output at specific intervals
    if (elapsedTime == 0 || (elapsedTime > 0 && elapsedTime % 5000 < 50)) {
      Serial.print("Time: ");
      Serial.print(elapsedTime/1000);
      Serial.println("s - M1=CW, M2=CCW, M3=CCW");
    }
  } else {
    // Next 20 seconds: Motor 2 CW
    analogWrite(M2_RPWM, motorSpeed);
    analogWrite(M2_LPWM, 0);
    
    // Debug output at specific intervals
    if ((elapsedTime >= 20000 && elapsedTime < 20050) || (elapsedTime > 20000 && (elapsedTime - 20000) % 5000 < 50)) {
      Serial.print("Time: ");
      Serial.print(elapsedTime/1000);
      Serial.println("s - M1=CW, M2=CW, M3=CCW");
    }
  }
}
